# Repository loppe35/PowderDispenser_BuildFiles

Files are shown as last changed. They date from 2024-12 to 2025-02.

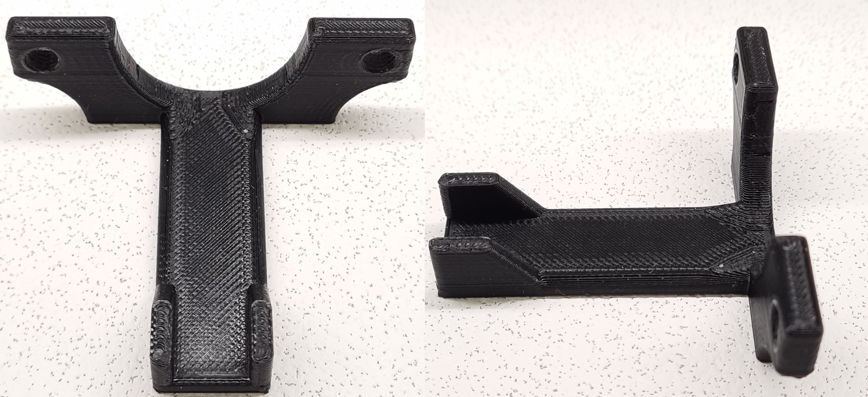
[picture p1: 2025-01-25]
Part_Pictures/LC_Test_Bracket.jpg

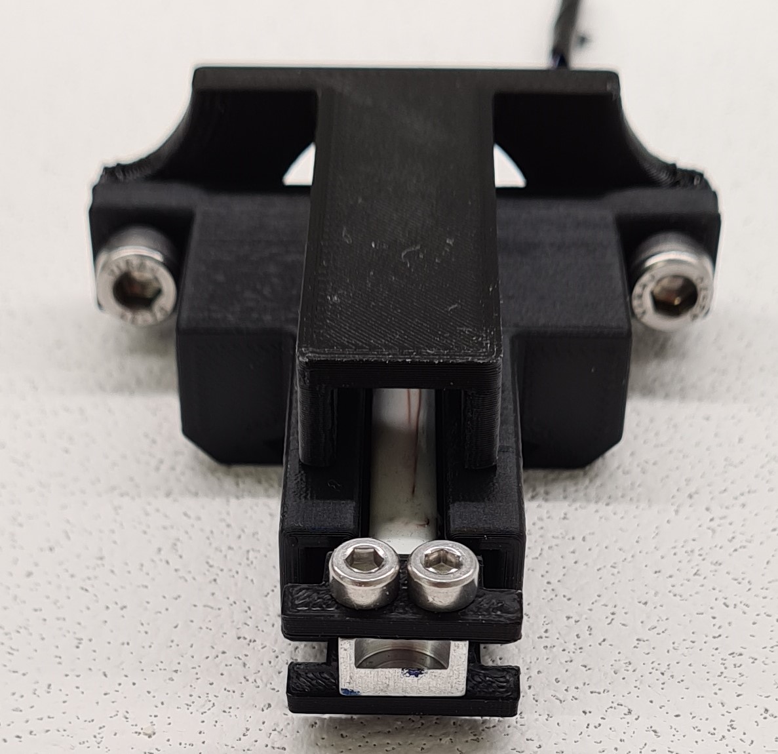
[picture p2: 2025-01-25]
Part_Pictures/LC_Housing_onTestBracket_f.jpg

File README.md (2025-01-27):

# 3D Models and CAD Designs

## Overview
This subrepository contains the STL and STEP files for [the Powder Dispensing and Weighing Module Project Repository](https://github.com/loppe35/PowderDispensing_and_Weighing_Module.git). These files represent the 3D models and detailed CAD designs necessary for manufacturing or prototyping the hardware components of the powder dispenser system.

A render depicting the complete system with explanatory labels:

Full Render Module

When printed, built and assembled the setup will look as follows:

Full System w. Dummy

Here a dummy input system is added for testing.

This repository also includes assembly instructions, renders, and labeled diagrams to help users understand the design and build the system efficiently.

---

## Repository Contents

### **1. 3D Model formats**
- **STL Files**: Ready for 3D printing on standard 3D printers.
- **STEP Files**: Suitable for detailed CAD work or integration into larger designs.

### **2. Detailed Component List**
This section provides the detailed names of STL and STEP files corresponding to each component:

#### **3D Printable parts**
Images and labeled diagrams of the assembled system and individual components are provided for visual reference:
1. **Load Cell Housing**
    Load Cell Housing
   - STL: `load_cell_housing.stl`
   - STEP: `load_cell_housing.step`
   - Function: Houses the load cell for precise measurements and serves as a rail for the dispensing head.

2. **Dispensing Head**
    Dispenser Head
   - STL: `dispensing_head.stl`
   - STEP: `dispensing_head.step`
   - Function: Holds the auger mechanism in place and aligns it for accurate dispensing.

3. **Syringe Bracket**
    Syringe Bracket
   - STL: `syringe_bracket.stl`
   - STEP: `syringe_bracket.step`
   - Function: Secures syringes and attaches to the load cell unigrippers.

4. **Structural Plates**
   - STL: `base_plate_front.stl`, `base_plate_back.stl`
   - STEP: `base_plate_front.step`, `base_plate_back.step`
   - Function: Provide structural integrity and mounting points for system components.

5. **Magnetic Stirrer Mount**
   - STL: `stirrer_magnet_mount.stl`
   - STEP: `stirrer_magnet_mount.step`
   - Function: Holds magnets for the magnetic stirring mechanism.

6. **Magnetic Stirrer Magnet Mount**
   - STL: `MagFanMount.stl`
   - STEP: `MagFanMount.step`
   - Function: Used with a fan and 2 pieces of 10mm x 10mm disc magnets to create a magnetic stirring setup.

7. **Stepper Motor Coupling Components**
   - STL: `StepperCoupling_In_Mag_5mm.stl`, `StepperCoupling_In_Mag_5mm.stl`
   - STEP: `StepperCoupling_In_Mag_5mm.step`, `StepperCoupling_In_Mag_5mm.step`
   - Function: Optional casing to hold a peristaltic pump and relay for dummy input testing.

8. **Dummy Input Components (Optional)**
    Dummy Input

   - STL: `dummy_input_casing_front.stl`, `dummy_input_casing_back.stl`
   - STEP: `dummy_input_casing_front.step`, `dummy_input_casing_back.step`
   - Function: Optional casing to hold a peristaltic pump and relay for dummy input testing.

9. **Peristaltic Pump Tube Mod (Optional)**
   - STL: `Pump_Mod.stl`
   - STEP: `Pump_Mod.step`
   - Function: Works as an adapter if one would need a smaller diameter tubing.

Additional renders and detailed images are available in the **Renders** and **Part_Pictures** directories.

#### **Additional Hardware Components**

This system requires additional non-3D-printed parts for full assembly. Below is a brief overview:
- **Microcontroller (e.g., Arduino)**: Executes the firmware for low-level control. The project was developed on a Sparkfun RedBoard Plus.
- **Stepper Motor**: Drives the auger mechanism for powder dispensing. Here, a small Nema 17 stepper motor was used, also supplied from Sparkfun.
- **Stepper Motor Driver**: Controls the stepper motor, with a little help from the microcontroller. A bulky yet convenient Sparkfun Prodriver was used.
- **Load Cell**: Measures the weight of dispensed material. For the intial development a 100g load cell from Sparkfun was used. However, a higher resolution and precision was needed at lower capacities, so a 50g load cell was scraped off a high precision jewelry scale.
- **ADC or Scale Unit**: Converts the load cell signal for digital processing. Sparkfun Qwiic Scale was used.
- **Drain Pump**: Manages liquid flow during cleaning or operations. A low-cost peristaltic pump was used
- **Relay**: Controls pumps and other external devices. Sparkfun Qwiic Relay
- **2x Disc Magnets**: Sits in magnetic stirrer magnet mount. The required disc magnets are 10mm x 10mm.

### **3. Assembly Instructions**
Detailed instructions on assembling the hardware components are included in this repository. These instructions cover:
- **Part Identification**: Matching 3D-printed components with their respective functions.
- **Assembly Steps**: Step-by-step guidance for building the system.
- **Hardware Integration**: Connecting additional components like load cells, stepper motors, and electronics.

---

## Usage

To use the files in this repository:

### **1. 3D Printing**
1. Open the STL files in your preferred 3D printing software.
2. Adjust settings based on your printer’s requirements.
3. Print the parts using compatible materials (e.g., PLA, ABS).

### **2. Printing Settings**
Prints were all carried out on an Ultimaker S3 with standard black PLA filament. The following settings were used:
- **Layer Height**: 0.2 mm – Standard resolution for balanced quality and print time.
- **Infill Density**: 20% – Provides a good balance between strength and material usage.
- **Print Speed**: 50 mm/s – Optimal speed to ensure quality without significantly increasing print time.
- **Print Temperature**: 210°C – Ideal for PLA; temperatures may vary for other materials.
- **Bed Temperature**: 60°C – Recommended for PLA to ensure good bed adhesion.
- **Retraction Distance**: 6.5 mm – Helps reduce stringing between print parts.
- **Retraction Speed**: 25 mm/s – Balances speed and effectiveness of retraction.
- **Cooling Fan Speed**: 100% – Essential for overhangs and fine details.
- **Support Structures**: Everywhere – Used when printing complex models to support overhangs.
- **Build Plate Adhesion Type**: Brim – Helps to prevent warping and ensures the first layers stick well.

Additional notes:
- **Support Variations**: Tree-style support structures were used only for the back part of the base and the dispensing head.
- **Printing Orientation**: All parts, except the dispensing head, must be printed "laying down":
  - Front parts should be laid on their backs.
  - Backplate parts should be laid on their fronts.

### **3. CAD Design**
1. Import STEP files into CAD software (e.g., Fusion 360, SolidWorks).
2. Modify or integrate the designs into larger systems as needed.

### **4. Assembly Guide**

#### **Preparation**
1. Acquire all necessary parts listed above.
2. Print the 3D components using the settings provided in the **Printing Settings** section.
3. Gather tools and equipment as specified in the equipment list.

#### **Step-by-Step Assembly**

1. **Front Plate Assembly**:
   - Attach the 40x40mm fan using 4x M4 hex-socket screws.
   - Attach the peristaltic pump with 2x M3 hex-socket screws. Ensure wires pass through the designated holes.

2. **Backplate and Stepper Motor Preparation**:
   - Attach the stepper motor to the motor mount.
   - Prepare the load cell housing by following.

3. **Motor Shaft Coupling**:
   - Insert 5mm x 2mm magnetic discs into the designated holes. Ensure alternating magnetic polarity.
   - Use tools or glue to secure magnets if necessary.

4. **Structural Assembly**:
   - Secure the front and back plates to the structural build plate.
   - Slide wires through appropriate holes to maintain organization.

5. **Final Components**:
   - Attach additional parts such as the dispensing head and magnet mounts.
   - Fasten the dispensing head rail and motor coupling.

6. **Dispensing Head Assembly**:
   - Insert the tube into the dispensing head cartridge.
   - Drill necessary holes and attach the auger mechanism with bearings and couplings.
   - Ensure smooth rotation and secure the components with glue if needed.

7. **Wiring**:
   - Mount the Arduino board and connect wires as per the circuit diagram.
   - Organize wires to ensure a clean setup.

#### **Verification**
1. Ensure all components are securely fastened.
2. Check wiring for proper connections.
3. Test mechanical movement and rotation before powering the system.

### **Flashing Firmware**
Make sure the installation guide from the `PowderDispenserCPP` directory is succesfully followed. That all the necessary files are cloned from gitHub repository.
1. **Install Dependencies**:
   - Navigate to the directory in the software submodule.
   - Run the following command to install Python dependencies:
     ```bash
     pip install -r requirements.txt
     ```
2. **Compile Firmware**:
   Connect the Arduino Uno board with the computer, and flash it though the chosen IDE(PlatfomIO was used during this project), with the main.cpp file located in the source files of the software repository.
3. **Configure System**:
   - Edit the `config.json` file to match your specific hardware and operational parameters.
---

## Contributing
If you make any modifications or improvements to the designs, please consider sharing your modified files back with the community. Contributions are encouraged under the CERN OHL-W v2.0 licensing terms to foster collaboration and innovation.

---

## License
The 3D models and CAD designs are released under the CERN Open Hardware License v2.0 (OHL-W). This allows you to use, modify, and distribute the designs under the terms outlined in the license.

Refer to the `LICENSE` file for detailed information.

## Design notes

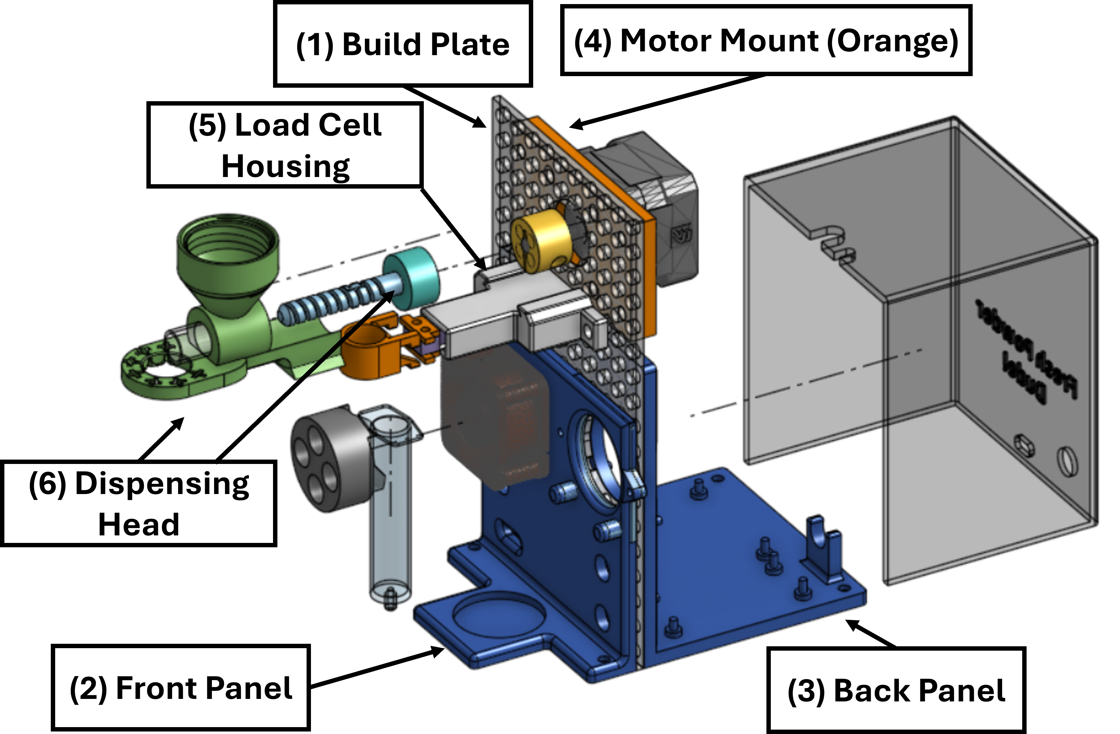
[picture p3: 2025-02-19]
Renders/FullRender_exploded.png

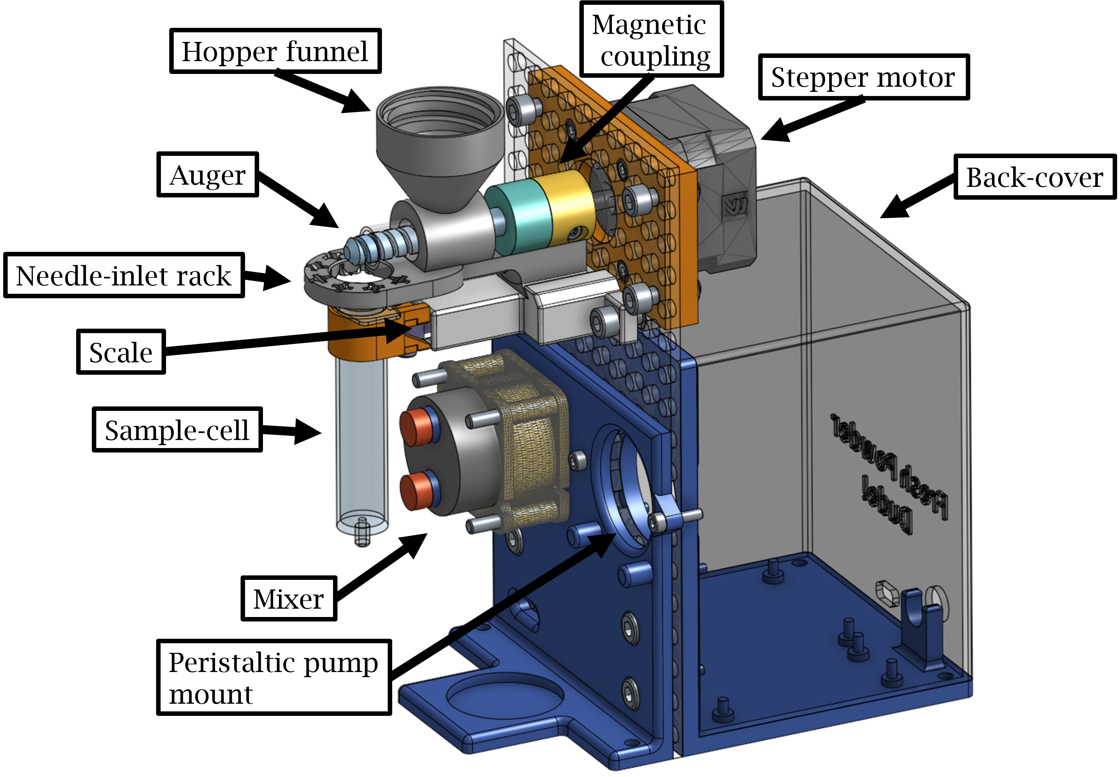
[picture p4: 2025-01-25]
Renders/FullRender.png

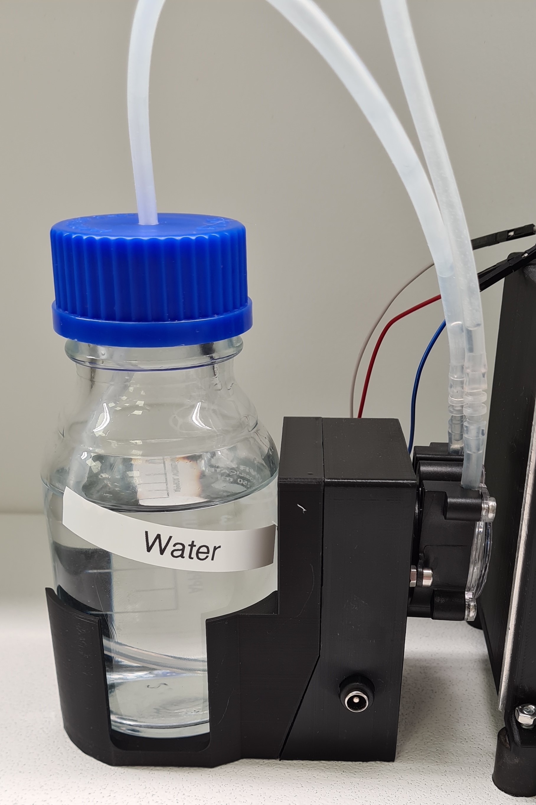
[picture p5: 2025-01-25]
Part_Pictures/Dummy_s.jpg

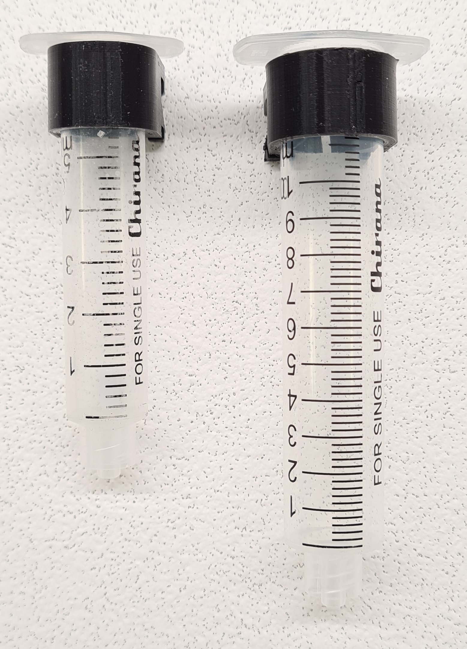
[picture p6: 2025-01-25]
Part_Pictures/SyringeBracket_f.jpg

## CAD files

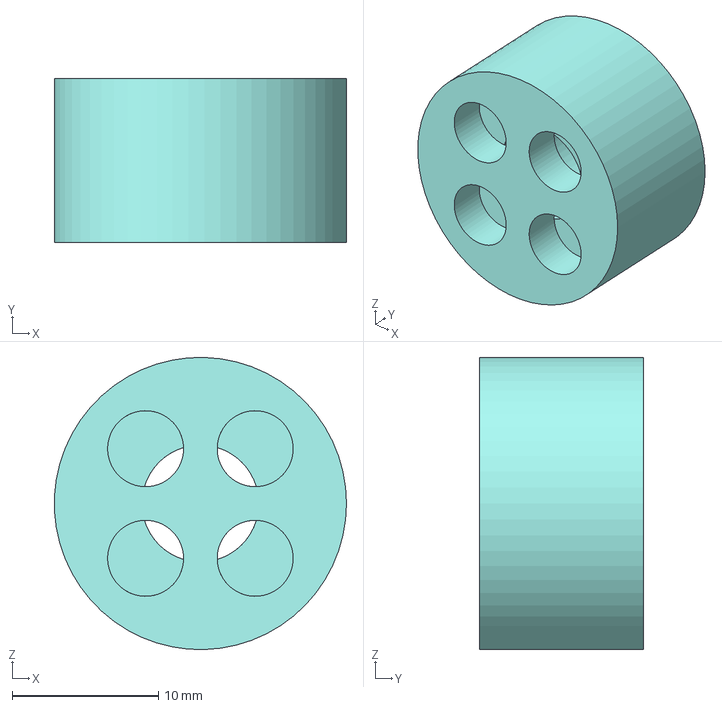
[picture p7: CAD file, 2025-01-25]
STEP_files/StepperCoupling_Out_Mag_5mm.step
20.0 x 11.2 x 20.0 mm

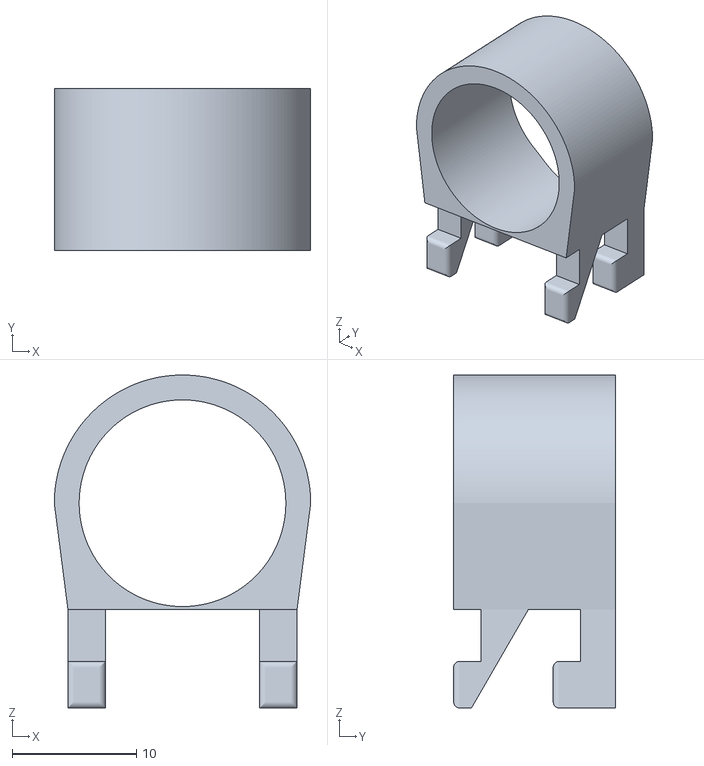
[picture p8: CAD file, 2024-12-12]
STL_files/SyringBracket_10ml.stl
20.6 x 13.0 x 26.7

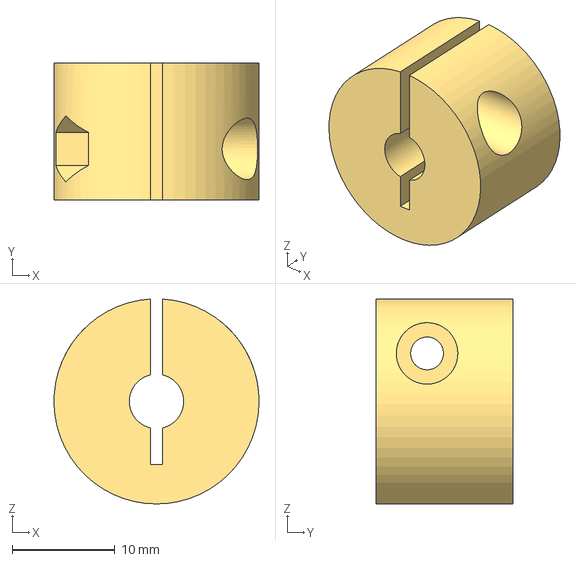
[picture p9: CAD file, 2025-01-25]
STEP_files/StepperCoupling_In_Mag_5mm.step
20.0 x 13.4 x 20.0 mm

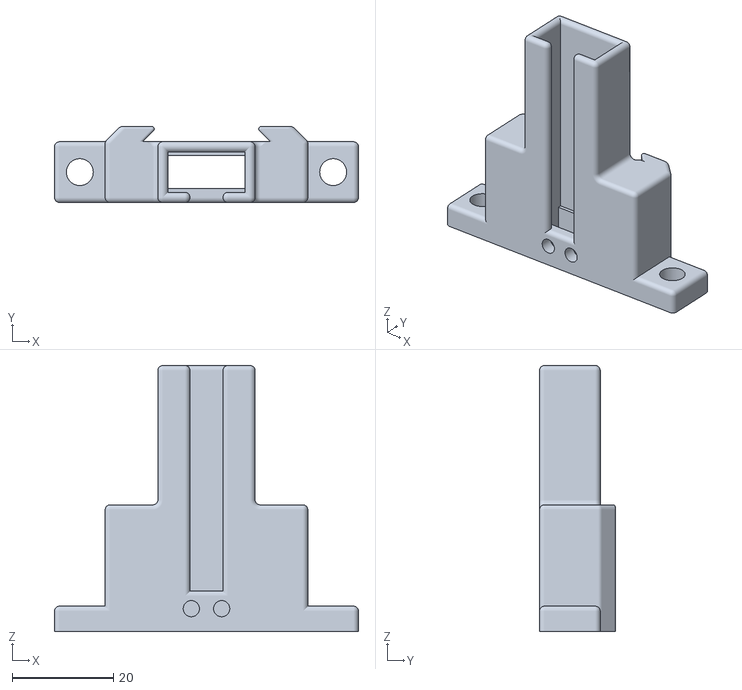
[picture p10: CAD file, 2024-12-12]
STL_files/LoadCellMount.stl
60.0 x 15.0 x 52.5

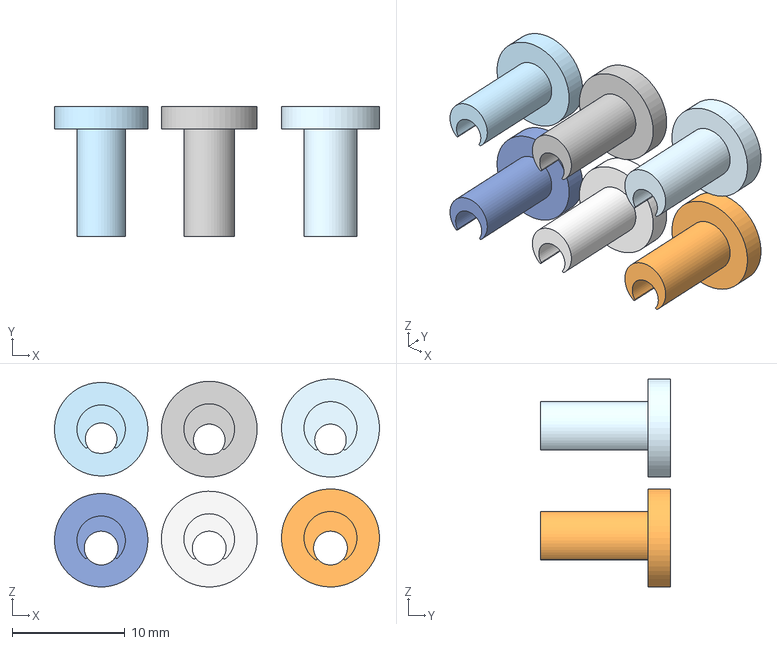
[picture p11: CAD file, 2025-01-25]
STEP_files/Pump_Mod.step
28.8 x 11.5 x 18.4 mm

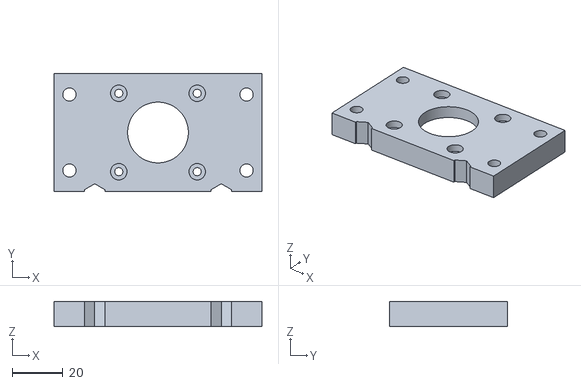
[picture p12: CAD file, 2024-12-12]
STL_files/StepperMount.stl
82.2 x 46.5 x 10.0

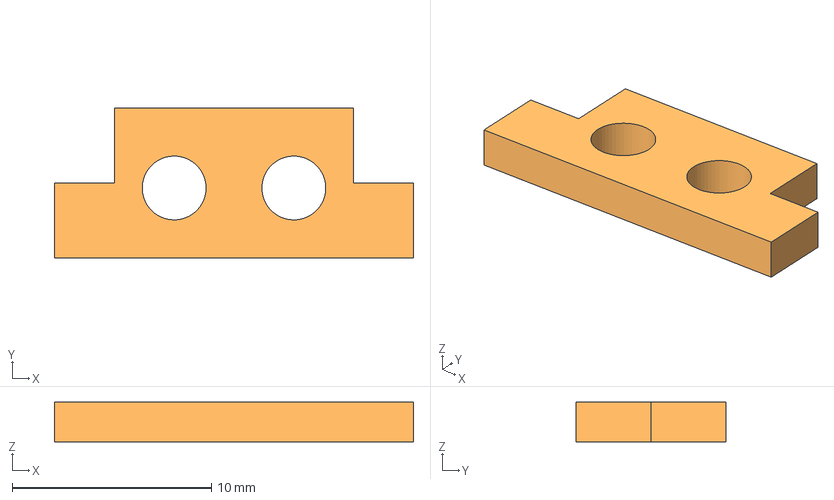
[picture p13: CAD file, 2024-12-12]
STEP_files/UniGripper_Bot.step
18.0 x 7.50 x 2.00 mm

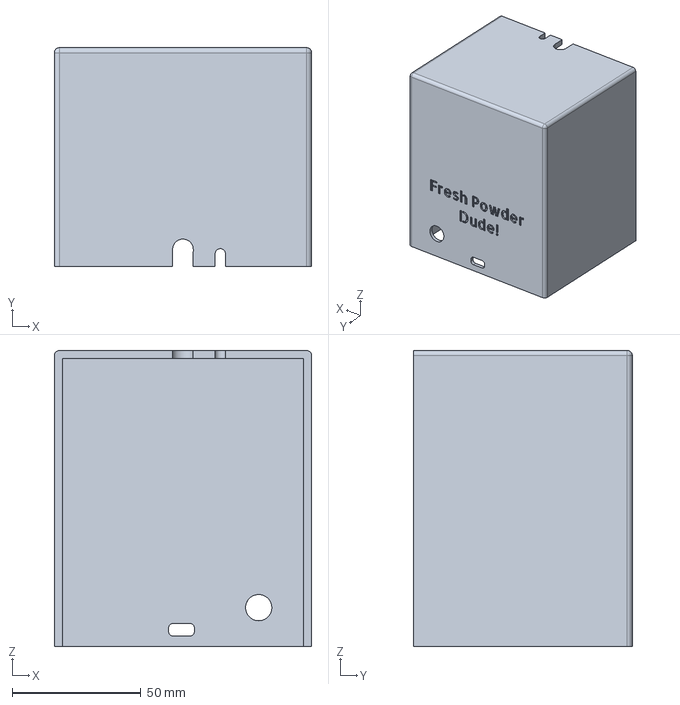
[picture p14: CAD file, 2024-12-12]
STEP_files/BaseBack_Cover.step
100.0 x 85.0 x 115.0 mm

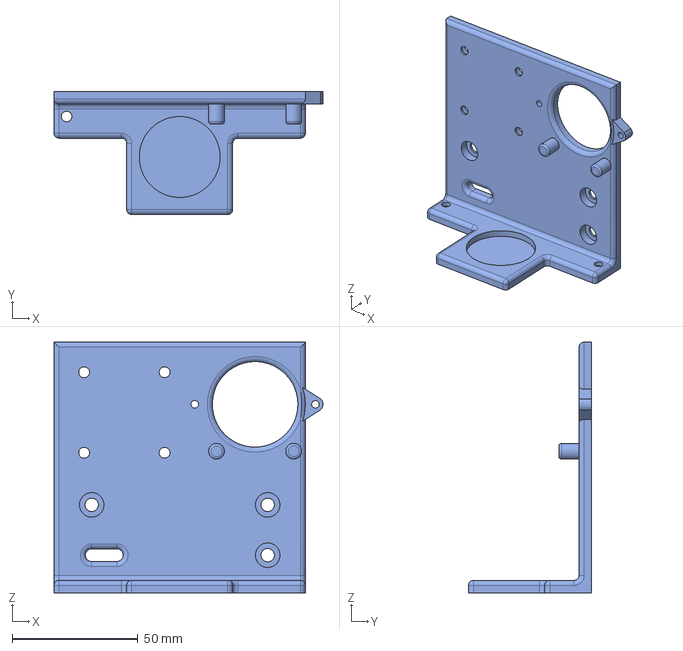
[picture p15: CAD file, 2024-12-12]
STEP_files/BaseFront.step
107.0 x 49.0 x 99.7 mm

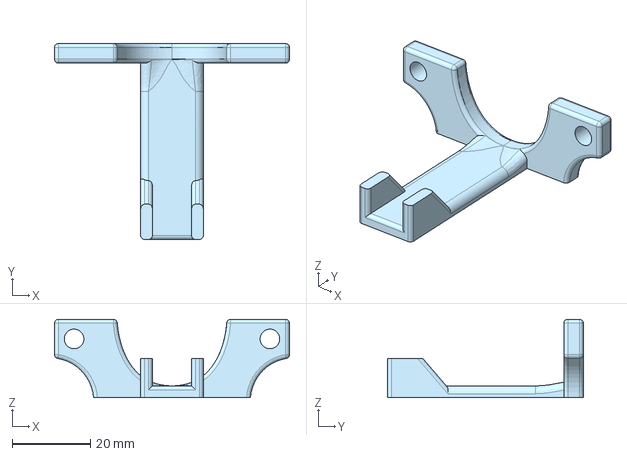
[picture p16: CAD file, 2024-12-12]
STEP_files/Mount_LoadCell_TestingBracket.step
60.0 x 50.0 x 20.0 mm

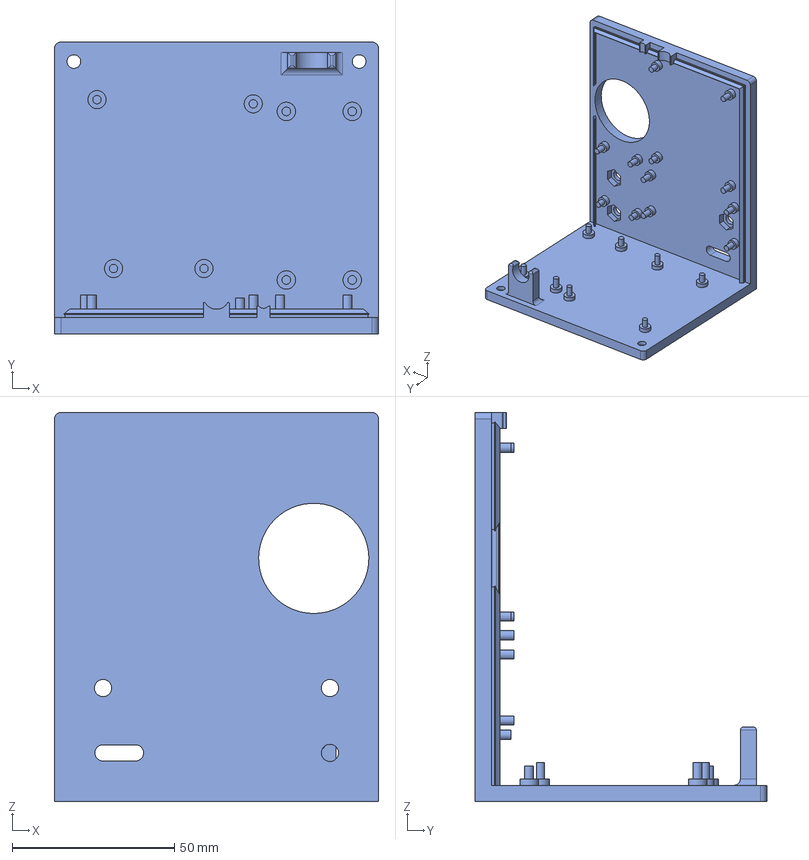
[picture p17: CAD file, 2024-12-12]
STEP_files/BaseBack.step
100.0 x 90.0 x 120.0 mm

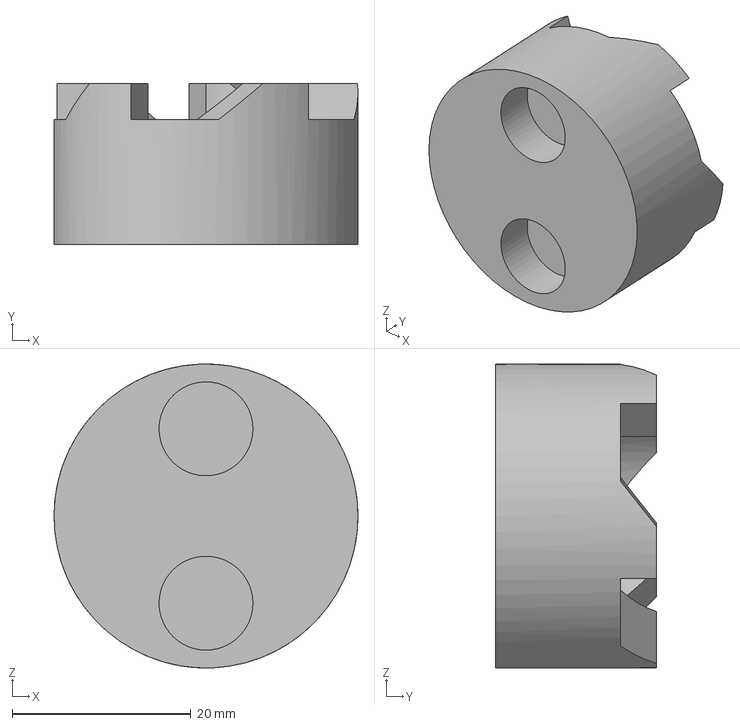
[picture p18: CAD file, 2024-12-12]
STEP_files/MagFanMount.step
34.0 x 18.0 x 34.0 mm

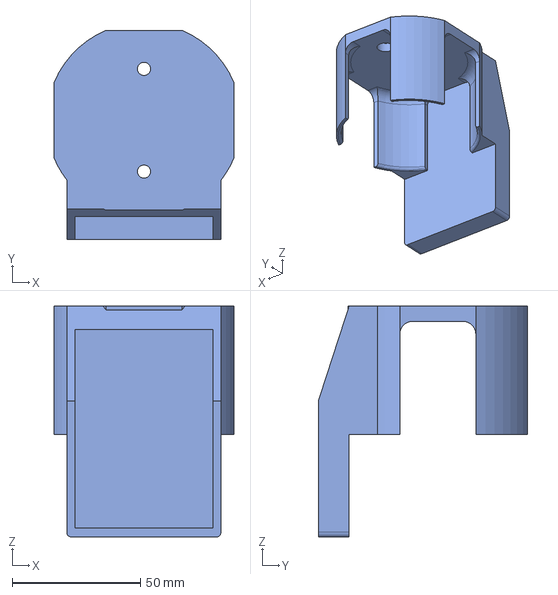
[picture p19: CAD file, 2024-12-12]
STEP_files/DummyInput_Back.step
70.0 x 81.5 x 89.9 mm

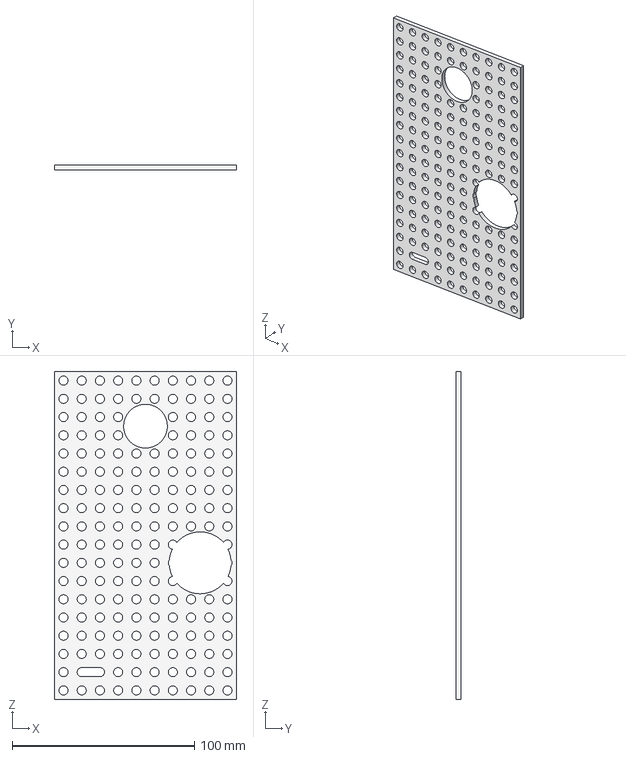
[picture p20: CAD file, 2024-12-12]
STEP_files/AttachmentPlate.step
100.0 x 3.00 x 180.0 mm

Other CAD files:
STEP_files/Mount_LoadCell.step
STEP_files/Mount_Stepper.step
STEP_files/SyringeBracket_10ml.step
STEP_files/DispensingHead_8mm.step
STEP_files/DummyInput_Front.step
STEP_files/SyringeBracket_5ml.step
STEP_files/UniGripper_Top.step
STL_files/BaseBack.stl
STL_files/BaseBack_Cover.stl
STL_files/BaseFront.stl
STL_files/DispensingHead_8mm.stl
STL_files/DummyInput_Back.stl
STL_files/DummyInput_Front.stl
STL_files/MagFanMount.stl
STL_files/Mount_LoadCell_TestingBracket.stl
STL_files/Pump_Mod.stl
STL_files/StepperCoupling_In_Mag_5mm.stl
STL_files/StepperCoupling_Out_Mag_5mm.stl
STL_files/SyringeBracket_5ml.stl
STL_files/UniGripper_Bot.stl
STL_files/UniGripper_Top.stl

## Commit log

2024-12-12 Submodule for hardware additions
    [AttachmentPlate.step, BaseBack.step, BaseBack.stl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]
2025-01-25 Readmes, Pics, and extra renders
    [Pump_Mod.step, Pump_Mod.stl, StepperCoupling_In_Mag_5mm.step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]
